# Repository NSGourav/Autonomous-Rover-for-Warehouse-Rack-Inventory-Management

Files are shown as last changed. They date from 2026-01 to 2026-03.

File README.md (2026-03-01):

# Autonomous-Rover-for-Warehouse-Rack-Inventory-Management
INTER IIT TECH MEET 14.0 MP1

## Overview

Designed and built an Autonomous Mobile Robot (AMR) for warehouse inventory management capable of:
- Autonomous navigation inside warehouse aisles
- Vertical scanning of racks up to 1.8 m
- QR-based rack identification
- Real-time inventory data logging
- The system integrates SLAM, ROS2 navigation, differential drive motion, and a belt-driven vertical lift mechanism into a unified workflow.

Official Problem Statement PDF: [Inter IIT Tech Meet 14.0 Problem Statement](https://drive.google.com/file/d/12ET33sytQ0gMRCpAS6UsOaBk7EDwTndu/view?usp=sharing)

## System Architecture

Two-layer architecture:
### Low-Level Control
- Arduino Mega
- DC motor control with encoder feedback
- Stepper motor control for vertical lift
- Emergency stop handling

### High-Level Control
- ROS2 middleware
- slam_toolbox (2D LiDAR SLAM)
- AMCL localization
- Nav2 (path planning + obstacle avoidance)
- OpenCV-based QR detection
- Inventory data logging

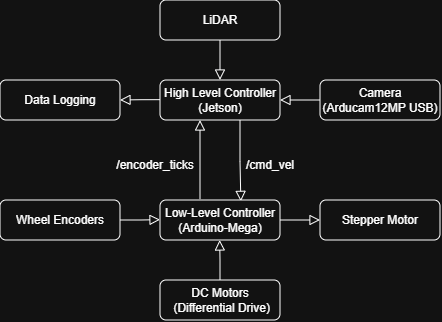
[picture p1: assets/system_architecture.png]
System Architecture


## Launch Files

## Results 
- ±25 cm positioning accuracy over 10 m
- QR detection < 1 second
- 90% QR detection rate
- Control loop at 20 Hz
- ~1 hour runtime (22.2V, 20Ah battery)

🏆 Final Rank: 6th out of 19 IITs

## Demonstration
🎥 Vertical Scanning: [Watch Here](https://drive.google.com/file/d/1KGMI8gQ0bd0-lW-TCqL113q4YaDr5LGW/view?usp=sharing)

🎥 Hardware Demo: [Watch Here](https://drive.google.com/file/d/1Vsa3Wl3Hw1EQ6sBA5-eVvMxNQFey-LZ9/view?usp=sharing)

🛠 CAD Model (Full Assembly): [View on GrabCAD](https://grabcad.com/yourlink)

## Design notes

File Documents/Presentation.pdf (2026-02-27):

# Autonomous Mobile Robot for Warehouse Inventory

## Team ID- 42

## INTER IIT TECH MEET 14.0

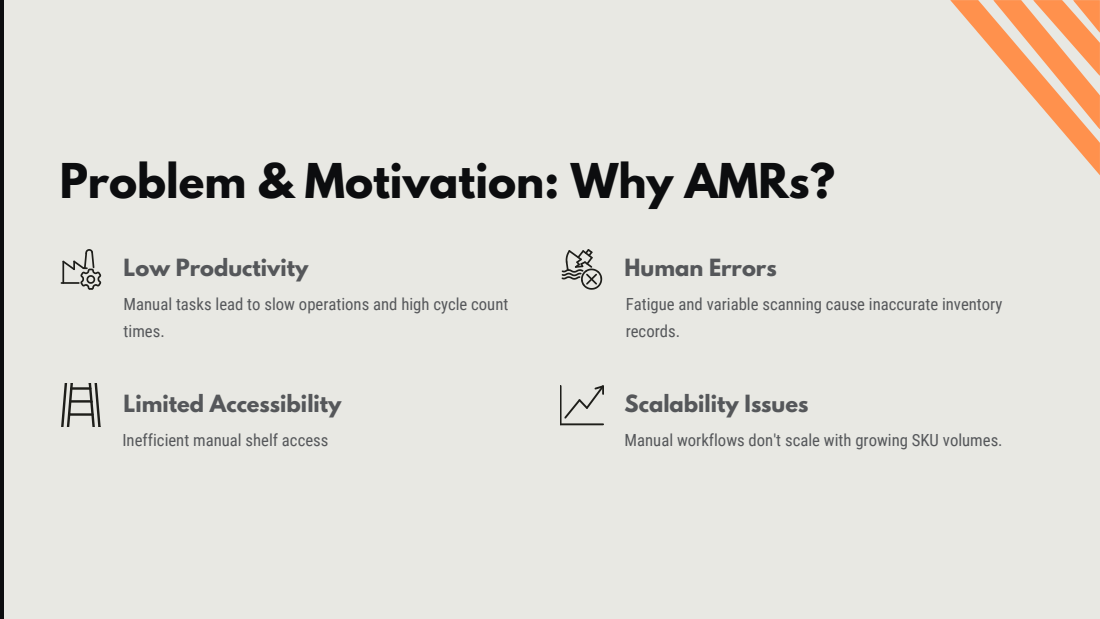
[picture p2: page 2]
Low Productivity; Human Errors; Limited Accessibility; Scalability Issues

Problem & Motivation: Why AMRs?

Manual tasks lead to slow operations and high cycle count
times.

Fatigue and variable scanning cause inaccurate inventory
records.

Inefficient manual shelf access

Manual workflows don't scale with growing SKU volumes.

# Executive Summary: Revolutionizing Inventory

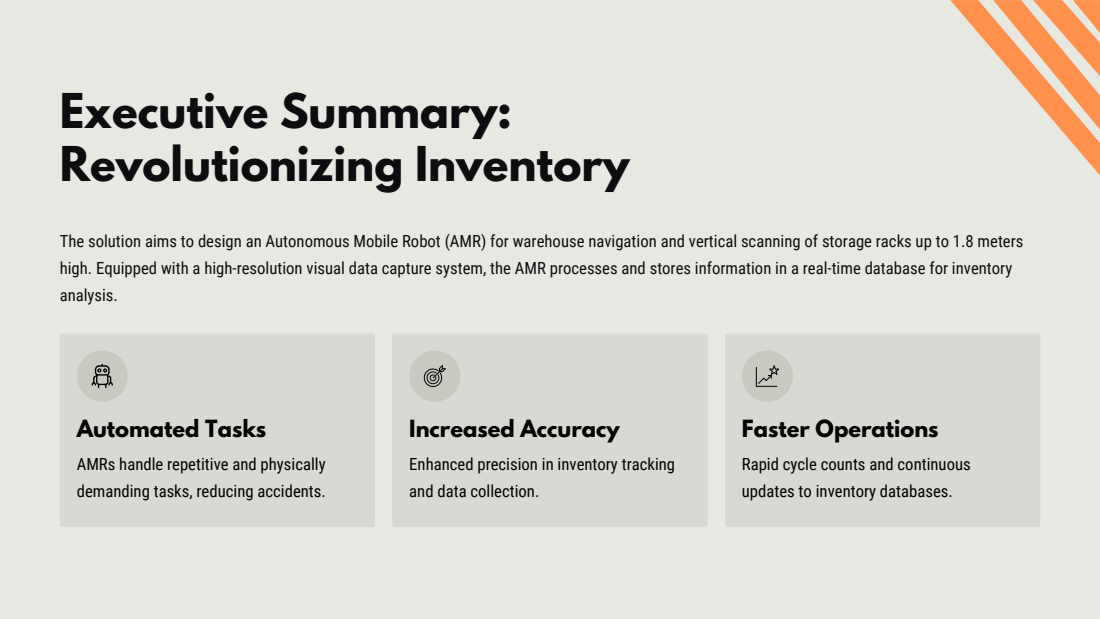
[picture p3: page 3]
Automated Tasks; Increased Accuracy; Faster Operations

The solution aims to design an Autonomous Mobile Robot (AMR) for warehouse navigation and vertical scanning of storage racks up to 1.8 meters
high. Equipped with a high-resolution visual data capture system, the AMR processes and stores information in a real-time database for inventory
analysis.

AMRs handle repetitive and physically
demanding tasks, reducing accidents.

Enhanced precision in inventory tracking
and data collection.

Rapid cycle counts and continuous
updates to inventory databases.

# Solution Approach & Key Metrics

Our AMR integrates SLAM-based navigation, QR scanning, a vertical lift, and data logging. Built with off-the-shelf components, it combines differential drive motion, a camera-based scanning module, and ROS 2 powered algorithms.

## Positioning Accuracy (X-Y)

±25 cm over 10 meters.

## Vertical Lift Accuracy (Z)

Less than 2 cm precision with stepper motor.

## QR Scanning Speed

Less than 1 second per QR code.

## Full Rack Scan

Within 3 minutes, including motion and positioning.

# Control Flow: High & Low Level

## Low-Level Controller (Arduino Mega)

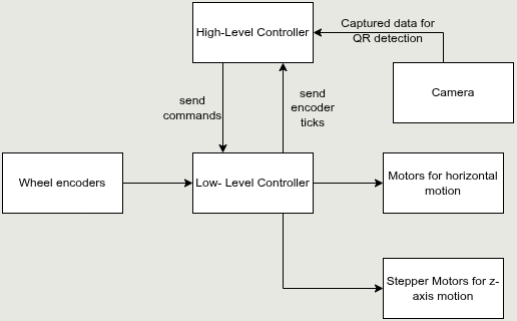
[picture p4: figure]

Provides real-time performance with sufficient GPIO pins and strong interrupt handling. Handles PWM signals and wheel encoder
feedback.

## High-Level Controller

Functions as the computational unit for autonomous navigation, perception, and data processing. Runs ROS 2 middleware for SLAM, localization, and path planning.

The High-Level Controller processes LiDAR data for mapping and visual data for QR code detection, storing information in warehouse servers.

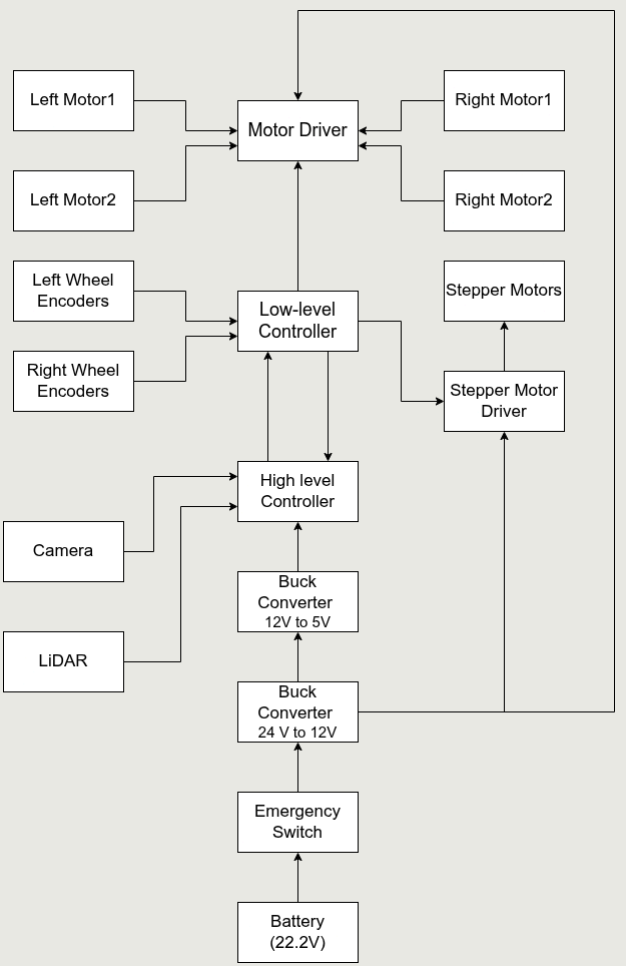
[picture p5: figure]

# Inter-connections between the various components used

# Hardware Design: Motion Systems

## Horizontal Motion: Differential Drive

Four DC motors provide high maneuverability and
precise control. Independent control allows forward/backward movement, turns, and zero-radius pivots for navigating narrow aisles.

## Vertical Motion: Belt-Driven Lift

A 1.5-meter aluminum double-extrusion profile guides a belt-driven linear actuation system. A NEMA stepper motor drives a timing belt, moving a V-slot gantry plate with the camera module.

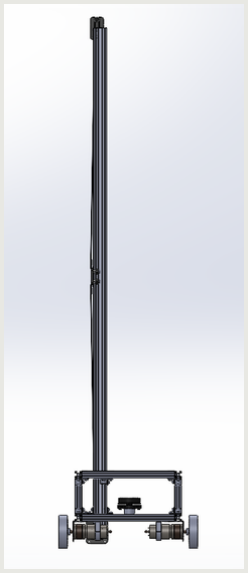
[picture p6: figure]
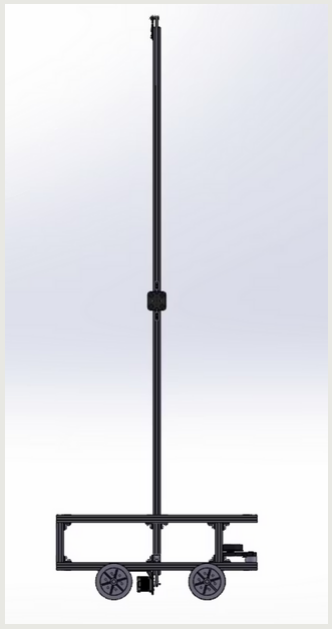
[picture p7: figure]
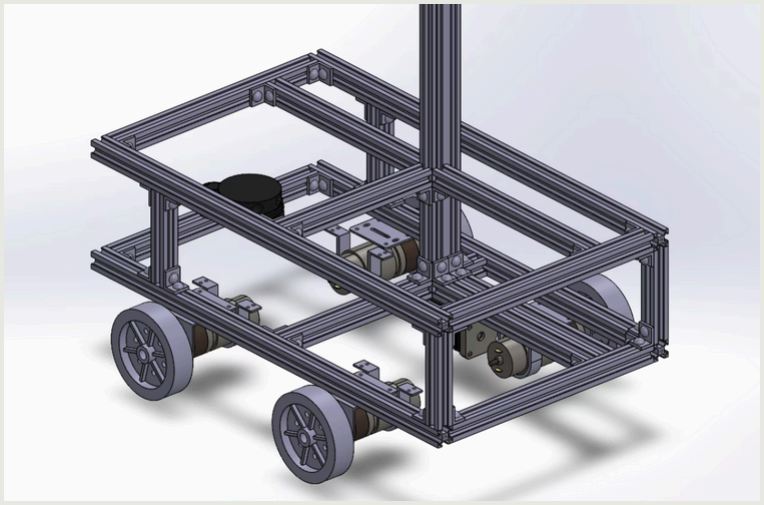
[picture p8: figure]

# Lift Mechanism: A Closer Look

A stepper motor drives a timing pulley connected to a reinforced belt running along the extrusion.
An idler pulley at the top maintains belt tension and eliminates backlash.
The belt is fixed to the V-slot gantry plate, so motor rotation converts directly into vertical motion.
The gantry plate uses four precision rollers to ensure stable, wobble-free travel along the extrusion.
This setup allows the camera module to move smoothly across the full 1.6-meter vertical range for scanning.

# How does it work?

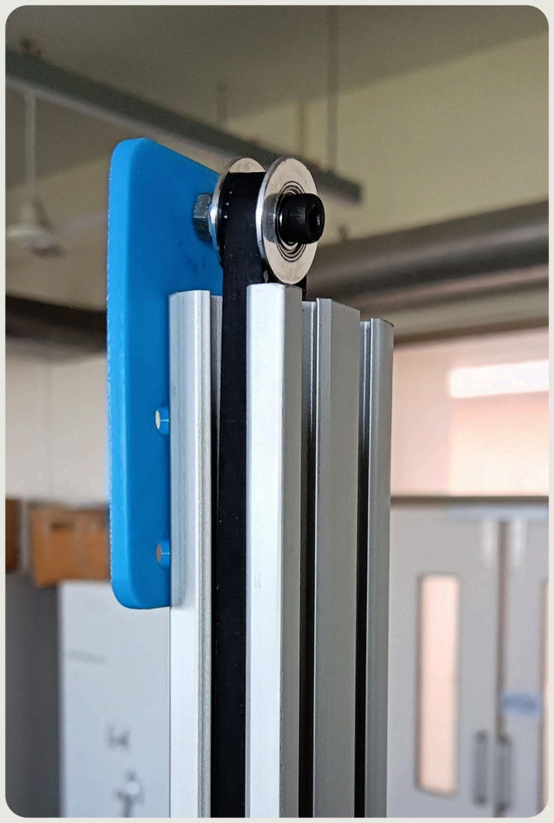
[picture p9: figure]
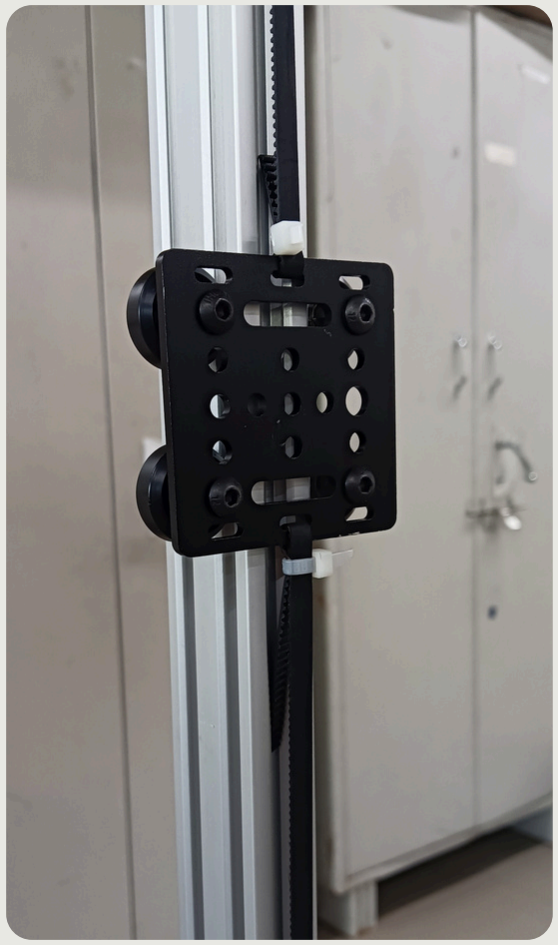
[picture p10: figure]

Pulley & Idler plate | V-slot gantry plate

# Why use belt-driven lift?

Provides high-speed, low-noise, and low-vibration motion suitable for precise camera scanning.
Avoids lead-screw limitations such as screw whip, high friction, reduced speed over long travel, and increased torque demand for tall lifts.
More efficient than telescopic masts, offering continuous, backlash-free motion without complex multi-stage assemblies.
Enables lighter construction, easier maintenance, and better cost-performance for long-range vertical actuation (up to ~1.8 meters).

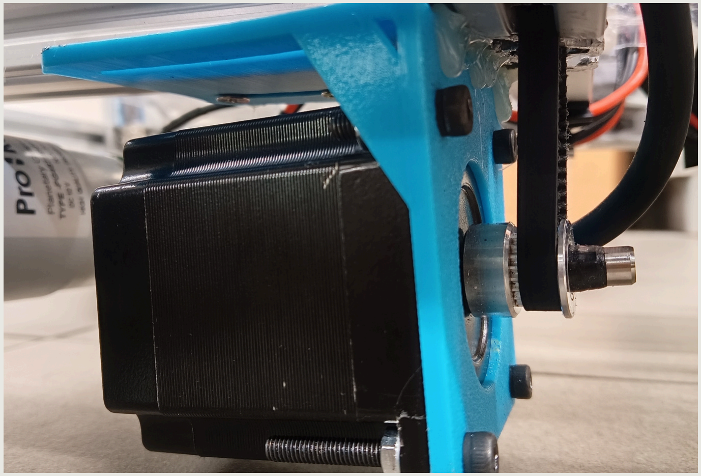
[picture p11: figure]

### Stepper with pulley controlling linear actuation of belt

# Gallery

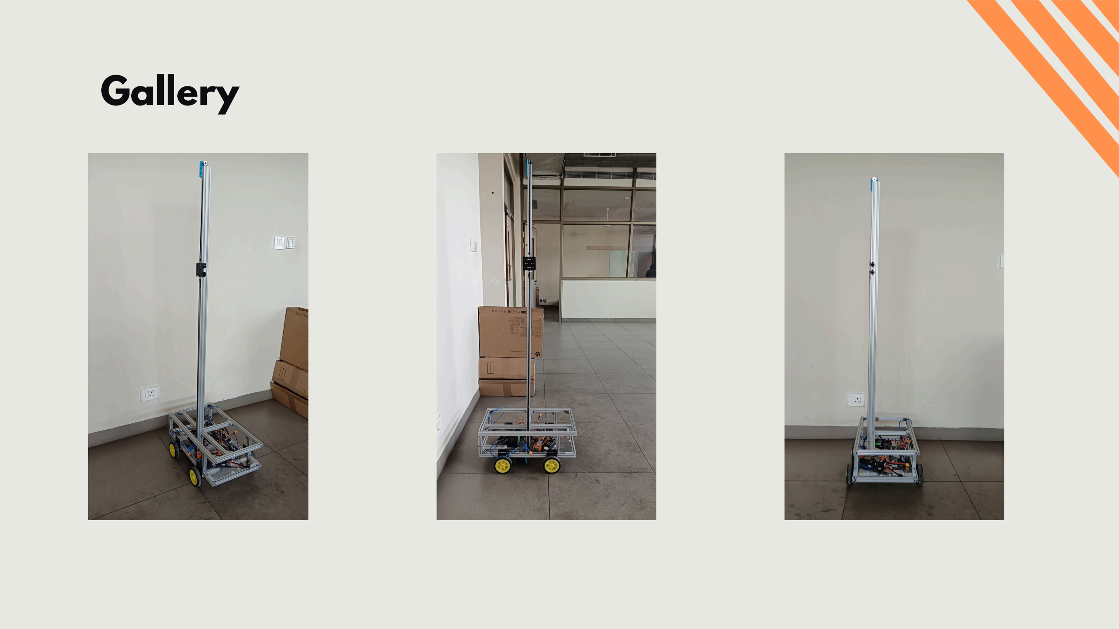
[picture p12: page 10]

# Software Architecture

The AMR's software is built on a modular, ROS 2-based architecture, integrating perception, motion control and navigation. The high level controller handles high-level tasks like localization, path planning etc. while the Arduino Mega manages low-level actuation and sensing.

01

## ROS 2 Operating Framework

Real-time communication, sensor integration, navigation algorithms, and modular scalability.

02

## SLAM & Localization

Uses slam_toolbox for 2D LiDAR-based SLAM, pose-graph optimization, and real-time map correction. AMCL localization for localizing the robot

03

## Navigation Stack (Nav2)

Handles global path planning, local obstacle avoidance, and collision-free trajectory computation.

04

## Vertical Actuation & QR Scanning

Stepper-driven Z-axis lift positions camera at predefined shelf heights. OpenCV + Python script detects and decodes QR codes and stores information locally.

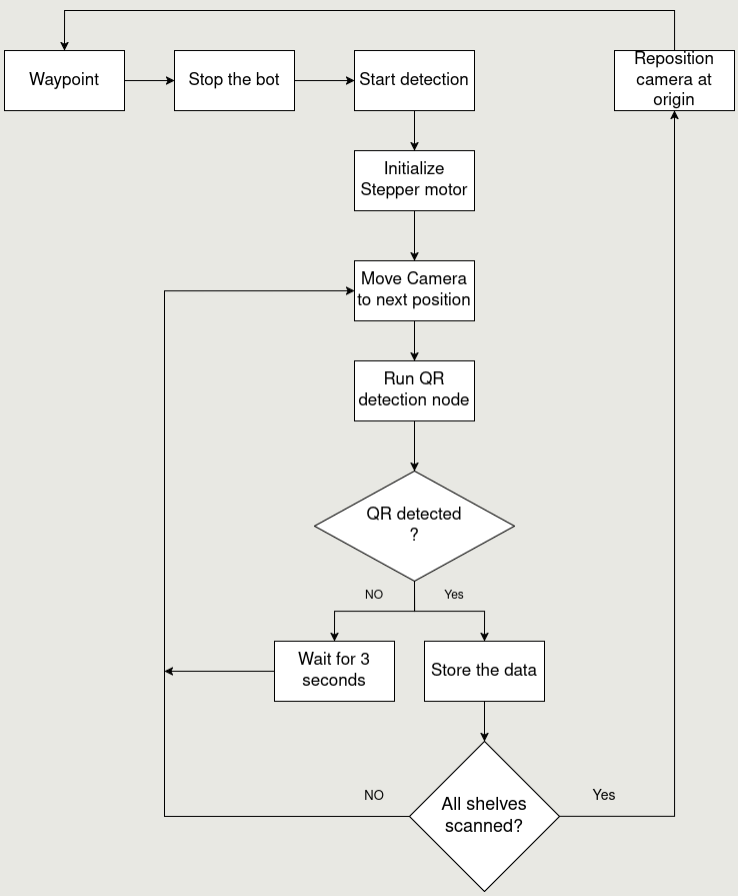
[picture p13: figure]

# QR code scanning and Camera Control mechanism

On reaching the racks, the following processes are being followed for detection of QR codes and acquiring the data stored in them and managing the inventory.

# Testing & Validation

Structured testing in a simulated warehouse environment validated the AMR's performance, reliability, and robustness across various parameters.

1

### Motion & Navigation

Positional accuracy of ±25 cm over 10m traversals. Max speed 0.6 m/s, stopping in 2 seconds.

2

### Vertical Lift System

Less than 2 cm vertical positioning accuracy, 10 mm/s lift speed for quick transitions.

3

### Perception & QR Scanning

QR code detection under 1 second. Full rack scan within 3 minutes.

4

### System Control Stability

Motion control loop operates at 20 Hz for stable autonomous behavior.

5

### Power & Endurance

Up to 1 hour of continuous operation under extreme condition (when using 22.2v ,20Ah battery).

# Future Improvements

Industrial level chasis building.
Recovery Behaviour.
Advanced scanning: dynamic shelf-height detection, adaptive camera, visual SLAM fusion. Implementing Autonomous Docking.

# THANK YOU

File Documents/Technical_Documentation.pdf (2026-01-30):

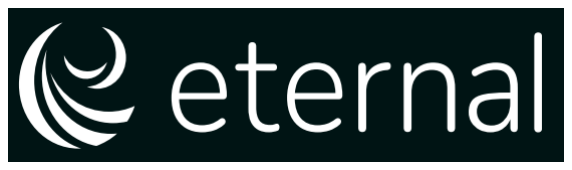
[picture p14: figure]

# Autonomous Rover for Warehouse Rack Inventory Management

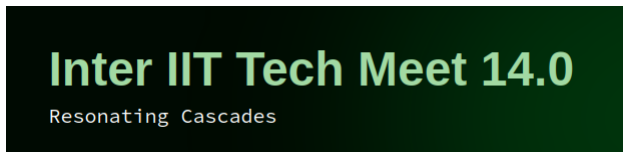
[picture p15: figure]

# End-Term Report

# Team ID: 42

# 6th December 2025

## End-Term Report

Abstract—This report describes the design procedure of an Autonomous Mobile Robot capable of navigating warehouse environments and performing vertical scanning operations on storage racks up to

### 2 meters high.. The AMR is equipped with a high-

resolution visual data capture system that scans the rack contents, processes the information, and stores it in a real-time database for inventory analysis and management. Detailed design concepts, accompanied by CAD files and videos that demonstrate live operation, are included as part of the performance evaluation.

I. EXECUTIVE SUMMARY

Inventory management is a mission-critical task for modern warehouses requiring precise tracking of Stock Keeping Units (SKUs), rapid cycle counts, and continuous updates to inventory databases. Traditionally, this has been done manually, where workers spend a large portion of their time walking long distances, searching for SKUs, climbing racks, and performing repetitive scanning tasks, which leads to fatigue, slow operations, and a high likelihood of human error. This is where Autonomous Mobile Robots (AMRs) greatly improve warehouse inventory management compared to traditional human-based systems by addressing several longstanding operational challenges. AMRs can take over repetitive and physically demanding tasks, reducing workplace accidents and increasing accuracy in less time—more suited to today’s fast paced world of quick orders and deliveries. They provide continuous, reliable, and data-driven inventory tracking that enhances productivity, ensures real-time visibility, and supports faster, error-free order fulfillment.

A. Overview of Solution Approach

Here, we are going to discuss our approach to designing an Autonomous Mobile Robot capable of navigating the warehouse and performing vertical scanning. The robot is built with commercially available off-the-shelf components that can be easily assembled anywhere, making it a suitable choice for this purpose.
The proposed solution integrates SLAM-based autonomous navigation, QR scanning, a vertical lift mechanism, and data logging. The robot uses a modular hardware architecture combining differential drive motion, a camera-based scanning module, and ROS 2 powered perception and planning algorithms.

The core challenge is to develop a vertical scanning mechanism capable of positioning and reading QR codes at pre-defined rack heights across a 2-meter vertical range, while ensuring accurate alignment, stable motion control, and reliable data acquisition.

B. Key Metrics

The performance of the autonomous robotic system has been evaluated and benchmarked across motion, sensing, perception, and operational endurance. The key performance metrics are summarized below:

- Positioning Accuracy (X–Y Axis)
– The robot maintains a positional accuracy of ±25 cm in the X–Y plane over a full traversal length of up to 10 meters.
- Vertical Lift Accuracy (Z Axis)
– The stepper-motor-driven lifting system achieves a precise vertical positioning accuracy of up to 2 cm.
- Z-Axis Lift Speed

– The maximum achievable velocity of the vertical lift stepper motor is 100 mm/s, enabling rapid elevation adjustments for scanning and object interaction.
- Motor Speed and Braking Performance

– The mobile base motors attain a maximum translational speed of 0.6 m/s.
– Motor stopping time from 0.6 m/s to a complete stop: 2 seconds.
- QR Code Scanning Performance

– Vision-based scanning detects and decodes QR markers in less than 1 second.
- Full Rack Scanning Efficiency

– The entire storage rack can be scanned within 2 minutes, including robot motion, positioning, and image acquisition cycles.
- LiDAR Range and Mapping Accuracy
– The LiDAR sensor provides accurate distance measurements up to 1.2 meters.
- System Control Frequency

– The primary motion control loop operates at 20 Hz, ensuring stable feedback for velocity regulation and localization updates in real time.
- Battery Life

– The on-board power system ensures up to 1 hour of continuous operation under typical motion and perception workloads.

II. PROBLEM UNDERSTANDING AND MOTIVATION

A. Productivity

Warehouse staff spend a lot of time walking through the warehouse, searching for SKUs, climbing racks and performing repetitive scanning tasks. This results in low operational throughput and high-cycle count times, especially in case of largescaled facilities.
AMRs can autonomously navigate through the pre-defined layouts of the warehouse, perform routine checks at intervals the operators are free to decide. This would reduce cycle-count times by 3-5 times and significantly improve operations.
B. Susceptibility to Human Errors

Manual scanning introduces inconsistencies due to operator fatigue, variable scanning angles, and improper documentation. This leads to inaccurate inventory records, misaligned stock levels, and higher chances of order fulfillment errors.
With controlled motion, fixed scanning geometry, and computer vision algorithms, AMRs ensure consistent barcode/QR readability and eliminate variability caused by human operators.
C. Limited Accessibility to Vertical Storage

Racks extending up to 2 meters require operators to climb ladders or use lifting equipment for scanning. This increases inspection time and introduces ergonomic and safety risks—particularly in narrow warehouse aisles.
The AMR integrates a vertical lift mechanism that moves the camera from bottom to top automatically. This ensures safe, fast, and complete scanning of all shelf levels without requiring human intervention.
D. Scalability

As SKU volume grows, manual inventory workflows do not scale well. Long traversal paths and repetitive scanning behaviors drastically increase workload and reduce operational agility, especially during peak seasons.
AMRs scale effortlessly—we would just need to deploy more robots or increase the scanning frequency. Their autonomous operation allows covering large areas efficiently and consistently. Robots can also operate continuously with predictable behavior and accuracy, enabling 24/7 inventory monitoring with minimal downtime.
E. Need for Data-Driven, High-Resolution Inventory Records

Modern supply chains rely heavily on fast, accurate, and data-rich inventory snapshots. Manual scanning rarely provides high-resolution images or structured digital logs, limiting traceability.
AMRs capture high-resolution shelf images, QR/Barcode metadata, and timestamped logs in a structured digital format suitable for analytics and automated reconciliation.
F. Alignment with Industry 4.0 and Smart Warehousing

Adopting AMR-based scanning aligns with Industry 4.0 goals—smart warehousing, data-driven analytics, and integration of cyber-physical systems. The shift from manual audits to automated continuous scanning significantly enhances operational visibility and scalability.
AMRs serve as cyber-physical systems that integrate mobility, perception, and real-time data communication—laying the foundation for smart warehousing, predictive analytics, and full automation.
G. Performance Objectives

Through the design and construction of a functional AMR suitable for Warehouse management system, we would like to achieve the following added improvements over the presently used solutions:

- Demonstrate a scalable warehouse automation solution
- Reduce manual efforts by more than 80%.
- Improve safety while scanning vertical heights.
- Achieve better accuracy with data logging and inventory management.
- Provide Real-Time Inventory Visibility
- Showcase Integration with Existing Warehouse Systems
- Optimize costs and durability.
- Prepare a safe, collision avoidant system for humans and robots to work together.

III. SYSTEM ARCHITECTURE

A. Power and Motor Control

The drive motors are powered directly from the robot’s primary battery system, chosen to match the current and voltage requirements of the motor drivers. High-current motor driver modules interface between the motors and the embedded control electronics. Each motor driver provides:

- Direction control
- PWM-based speed control
- Overcurrent prevention
- Heat-sinks for thermal protection

This ensures reliable motor performance even during extended operation in 0°C–40°C warehouse conditions.

B. Control Flow Architecture

The robot uses a two-tier control system to balance high-level intelligence and processing power with low-level real-time responsiveness for achieving maximum output in minimum time.

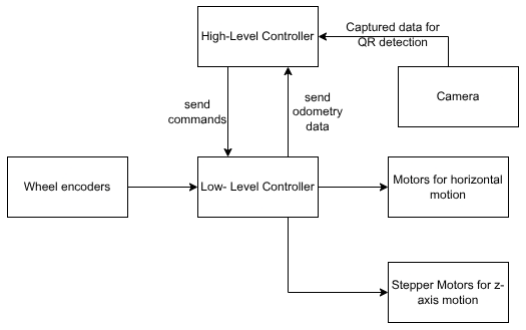
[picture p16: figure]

Fig. 1: 2-level Controller

1) Low-Level Controller: The Arduino Mega 2560 Rev3 board has been used as the onboard controller because it provides an excellent real-time performance with sufficient GPIO pins, multiple hardware serial ports, strong interrupt handling capabilities, seamless compatibility with motor drivers. It is used for:
- Receiving high-level commands from the high level controller Jetson Nano through UAR-T/I2C/serial
- Generating PWM signals for motor drivers
- Executing differential-drive kinematics in real time
- Handling wheel encoder feedback
- Ensuring immediate response for braking or velocity correction

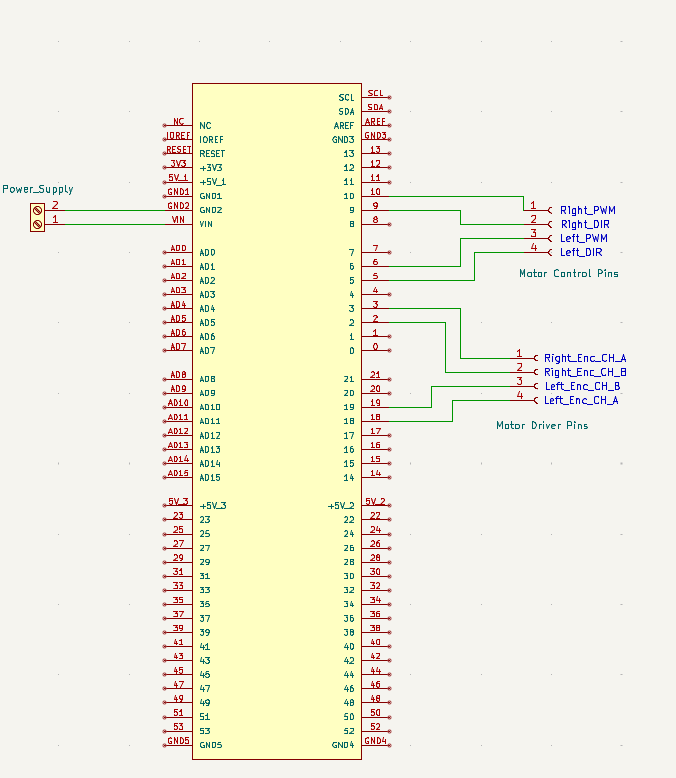
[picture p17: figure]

Fig. 2: Schematics

2) High-Level Controller: The NVIDIA Jetson Nano functions as the high-level computational unit responsible for autonomous navigation, perception, data processing, and system coordination. It runs the full ROS 2 middleware, acting as the central node that integrates the robot’s sensing, decision-making, and communication subsystems. It handles the following critical tasks:
- ROS2 based Autonomous Navigation The Nano runs ROS 2 nodes for:
– SLAM (Simultaneous Localization and Mapping) Using LiDAR data to construct and update a real-time 2D map of the warehouse. – Localization Tracking the robot’s position on the generated map.
– Path Planning and Path Following Generating obstacle-free trajectories and converting them into high-level movement commands. – The LiDAR is directly connected to the Jetson Nano via USB or serial, and its data is processed through ROS 2 packages such as slam-toolbox, nav2, or equivalent.

Algorithm 1 SLAM Algorithm for Autonomous Mobile Robot (AMR)
1: Initialization:
2: Initialize robot pose estimate xˆ0
3: Initialize map representation M0 (empty or prior map)
4: Initialize motion model and sensor model parameters
5: Set time step t = 0

6:
7: while robot is operational do
8: | t ← t + 1
9: | Input:
10: | Receive control commands ut (odometry,
| wheel encoders)
11: | Receive sensor measurements zt (LiDAR)

12:
13: | Map Update:
14: | Add new landmarks or update existing ones
| in Mt
15: | Update occupancy grid / feature map using
| zt and xˆt

16:
17: | Output: Updated pose estimate xˆt and map
| Mt
18: end while
- Sensor Fusion and Perception The Nano is
| connected to LiDAR for scanning the environ-
| ment for running Simultaneous Localization
| and Mapping (SLAM) algorithms and generat-
| ing point clouds. The visual data captured in
| the camera is also processed by the Nano for
| QR code detection and data retrieval. The data
| obtained is stored in the Warehouse servers.
- Server Communication and Monitoring The
| Jetson Nano maintains wireless connectivity
| with warehouse infrastructure to:
| – Upload camera scans
| – Stream robot status
| – Send mapping/navigation logs
| – Fetch mission instructions or scheduled
| scanning tasks
| This allows real-time synchronization between
| the robot and the warehouse management
| system (WMS).
| IV. HARDWARE DESIGN

The hardware is built with commercially available off-the-shelf components. The vertical lifting subsystem is designed to enable precise, stable, and repeatable elevation of the camera module for high-rack inventory scanning within warehouse environments.

A. Horizontal motion

The horizontal motion of the AMR is achieved by a differential drive mechanism, designed for high maneuverability, robustness, and precise motion control within warehouse environments.
1) Differential Drive Configuration: The platform utilizes four DC motors, arranged with two motors on each side to maximize traction, payload capacity, and stability during operation. They are controlled by commands from the onboard Microcontroller. Independent control of left and right motor groups allows the robot to: Move forward/backward by driving both sides in the same direction, perform turns by differential wheel speeds, execute zero-radius (pivot) turns by driving the sides in opposite directions. This configuration enables smooth navigation through narrow warehouse aisles, tight corners, and dynamic environments with obstacles and human movement.
B. Vertical Motion and Lift Mechanism

The robot utilizes a 2-meter aluminum doubleextrusion profile as the primary structural guide, offering high rigidity, low weight, and excellent resistance to flexing under vertical loads.
A belt-driven linear actuation system is implemented to provide smooth and controlled vertical motion. At the base of the extrusion, a NEMAseries stepper motor is mounted securely using a motor-mounting plate. The motor shaft drives a timing pulley, which engages with a reinforced GT2/HTD timing belt running along the length of the extrusion.
At the upper end of the extrusion profile, an idler pulley assembly is positioned using an idler plate. The belt passes over this idler pulley, allowing for proper tensioning and minimizing backlash. The belt loop is routed such that one segment is fixed to a V-slot gantry plate equipped with precision rollers. As the stepper motor rotates, the belt’s motion directly translates into linear displacement of the gantry plate along the extrusion.
The V-slot gantry plate provides stable 4- or 6-wheel contact with the extrusion profile to ensure smooth, low-friction vertical motion while maintaining alignment under lateral forces. The camera module is rigidly mounted to this gantry plate, enabling it to traverse 1.60-meter height for rack scanning operations.

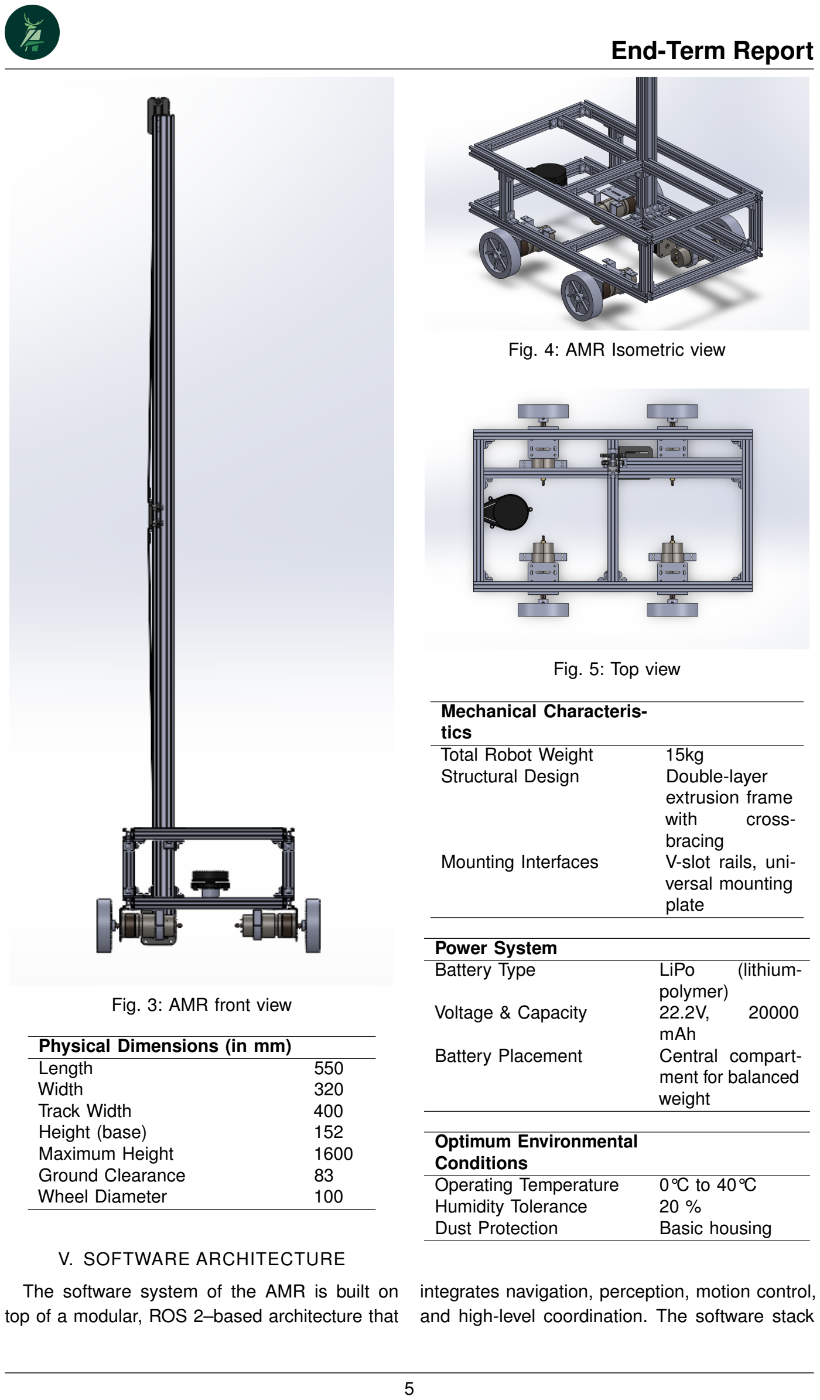
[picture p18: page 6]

Fig. 3: AMR front view

Physical Dimensions (in mm)
Length | 550
Width | 320
Track Width | 400
Height (base) | 152
Maximum Height | 1600
Ground Clearance | 83
Wheel Diameter | 100
V. SOFTWARE ARCHITECTURE

The software system of the AMR is built on top of a modular, ROS 2–based architecture that

Fig. 4: AMR Isometric view

Fig. 5: Top view

Mechanical Characteristics
Total Robot Weight | 15kg
Structural Design | Double-layer
extrusion frame
| with | cross-
| bracing
Mounting Interfaces | V-slot rails, uni-
versal mounting
| plate

Power System
Battery Type | LiPo | (lithium-
| polymer)
Voltage & Capacity | 22.2V, | 20000
| mAh
Battery Placement | Central compart-
ment for balanced
| weight

Optimum Environmental
Conditions
Operating Temperature | 0°C to 40°C
Humidity Tolerance | 20 %
Dust Protection | Basic housing

integrates navigation, perception, motion control, and high-level coordination. The software stack

Current Analysis | Value
Jetson Power Draw | 2A
Arduino Mega (each) | 0.5A
DC Motor Power (ideal) | 2A × 4 = 8A
DC Motor Power (maximum)

4A × 4 = 16A

Stepper Motor (each) | 2.8A
Camera & LiDAR | Powered by Jet-
| son
Motor Driver Rating | 10A | (normal),
30A (peak)
Stepper Motor Driver Rat- ing | 4A

runs primarily on the NVIDIA Jetson Nano, while low-level actuation is handled by the Arduino Mega. The system supports autonomous warehouse navigation, LiDAR-based mapping, Z-axis scanning, QR-code detection, and structured inventory data storage.

A. Operating Framework: ROS 2

The robot uses ROS 2 as its core middleware. ROS 2 provides:Real-time communication between software nodes, Sensor integration, Navigation algorithms, Visualization tools, Modular software scalability
ROS 2 nodes running on the Jetson Nano interact with the LiDAR, Z-axis lift systems, camera, and the Arduino Mega.
B. SLAM and Localization

For mapping and continuous localization, the system uses slam toolbox, a ROS 2 package optimized for real-time warehouse-scale SLAM.

- 2D LiDAR-based SLAM
- Pose-graph optimization
- Loop closure
- Real-time map correction
- Persistent map saving
C. Odometry

Odometry is obtained by fusing multiple sensor sources:

- Wheel Encoders measure how much the wheels have rotated, allowing the robot to estimate how much it has moved. When we combine these measures for left and right wheels, we can get the position and orientation.
D. Navigation Stack

The autonomous navigation layer is built using Nav2, the standard ROS 2 navigation framework. Nav2 handles:

- Global path planning
- Local obstacle avoidance
- Costmap generation
- Path smoothening
- Behavior trees for mission execution

Using LiDAR data and the SLAM-generated map, Nav2 computes collision-free trajectories between rack aisles and scanning locations.

E. High-Level Command Execution

The Jetson Nano acts as the decision-making brain. All path planning, SLAM, and perception algorithms run on the Nano. Once the desired linear and angular velocities are computed, they are transmitted to the Arduino Mega using a serial protocol.
Jetson to Arduino Communication:
- Jetson Nano publishes /cmd vel velocity commands
- A bridge script converts ROS 2 velocity messages into serial commands
- Arduino Mega receives:
- Target linear velocity
- Target angular velocity
- Motion mode (forward, rotate, stop)
- Arduino handles real-time PWM generation for all four motors

This ensures smooth, deterministic execution of motion commands without OS-induced delays on the Jetson.

F. Imaging & QR Code Scanning Pipeline

The AMR performs vertical rack scanning using a stepper-driven Z-axis lift equipped with a camera. The scanning pipeline operates in discrete height levels that match warehouse shelf elevations.
1) Controlled Z-Axis Positioning: During a scan:
- Nav2 positions the robot in front of the rack.
- Motion is halted to eliminate vibrations.
- The Z-axis controller raises/lowers the camera to predefined shelf heights.
- Stabilization delay ensures sharp images.

Algorithm 2 Camera Position Control using Stepper Motors
1: Input: Target rack heights H = {45, 87, 130} cm
2: Constants:
3: | Srev = 200 steps per revolution
4: | Drev = 5.027 cm belt travel per revolution
5: | Scm = Srev/Drev steps per cm

6:
7: ROS2 Node (Publisher):
8: Initialize prev height = 0
9: for each h in H do
10: Compute incremental distance:

d = h − prev height

11: Compute required steps:

steps = d × Scm

12: | Publish | steps | on | topic
/camera_lift/steps
13: Update previous height:

prev height = h

14: end for
15: Arduino Node (Subscriber):
16: while | message | received | from | topic
/camera_lift/steps do
17: | Read incoming step command steps
18: | Drive the stepper motor for steps steps
19: | Stop motor movement
20: | Wait for 5 seconds to capture QR
21: end while

22:
23: Camera Operation:
24: for each halt position do
25: | Run detection script
26: | Extract QR data and append to JSON file
27: end for
28: End Algorithm
2) QR Code Detection (OpenCV + Python): A Python script running on the Jetson Nano uses OpenCV QR detection to process each captured image:
- Detects and decodes QR codes
- Extracted | data | is | of | the | form
RACKID_SHELFID_ITEMCODE | which | is
parsed and stored in a CSV file
- Validates code integrity
- Handles low-contrast cases with preprocessing (thresholding, sharpening, etc.)

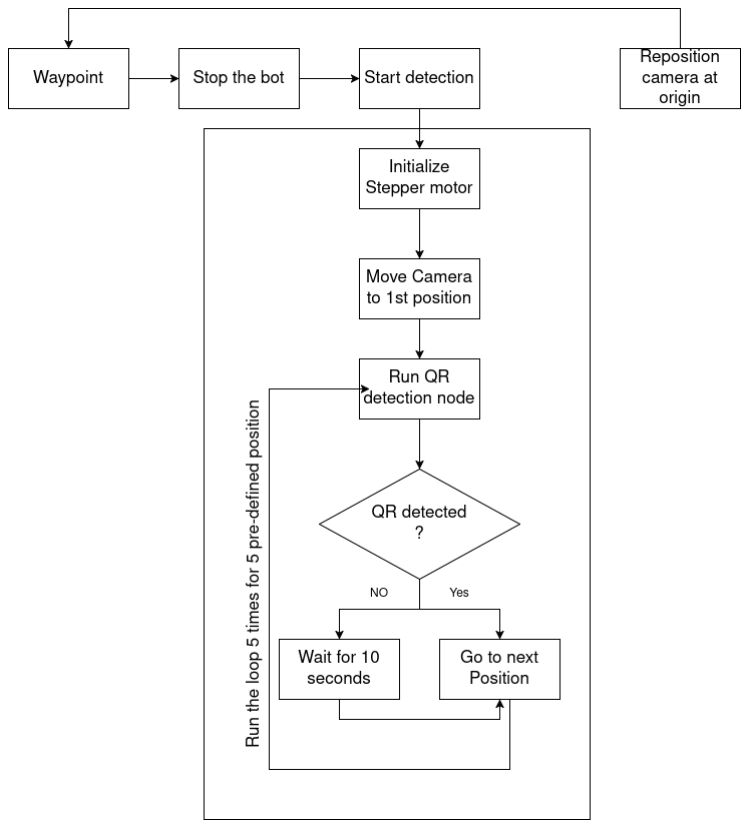
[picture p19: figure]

Fig. 6: QR detection mechanism

VI. INTEGRATION AND CONTROL

The autonomous mobile robot (AMR) integrates hardware and software components to achieve precise navigation and task execution within warehouse environments. Control and motion execution are handled using the ROS2 framework, which provides modular and real-time communication between nodes.

A. Motion Control
- The AMR uses ROS2 Control to interface with motor drivers and sensors, providing a hardware-agnostic control layer. Wheel velocities and actuator commands are sent via ROS2 controllers, allowing seamless integration with higher-level planning.
- Sensor feedback, including wheel encoders
- A PID controller processes velocity errors and generates motor commands, ensuring accurate tracking of the desired trajectory.
B. Navigation
- The AMR employs Nav2 stack for autonomous navigation. It performs mapping, localization, path planning, and obstacle avoidance within the warehouse.
- Real-time sensor data is fused to create an up-to-date occupancy grid, which is used by the planner to compute collision-free paths.

- Motion commands from the planner are translated into wheel velocity setpoints, which are tracked by the PID controller via ROS2 Control.
C. Integration Workflow
- High-level navigation goals are sent to the Nav2 stack, which computes safe paths for the robot to follow.
- ROS2 topics and services handle communication between the navigation stack, perception nodes, and low-level control nodes.
- Safety mechanisms, including emergency stops and collision detection, are integrated to override commands if required, ensuring reliable and safe operation.

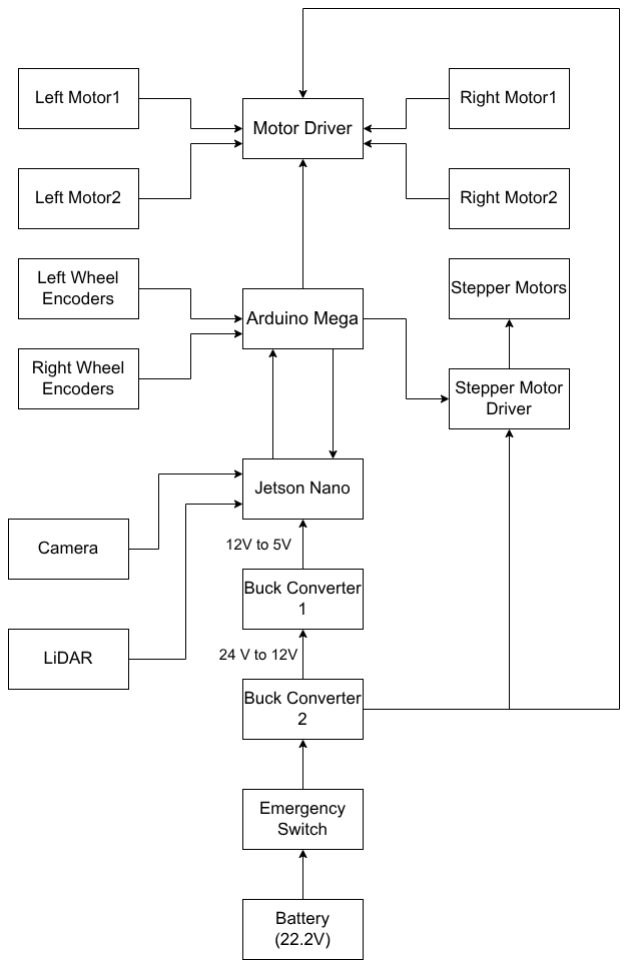
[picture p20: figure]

Fig. 7: Circuit Connection Flow

Algorithm 3 Updating positions from Wheel Encoder
1: Initialization:
2: Set PID gains: Kp, Ki
, Kd
3: Initialize error, integral, and derivative terms to zero
4: Initialize robot pose variables (x, y, θ)

5:
6: Loop executed every fixed time interval: 7: Read the current encoder tick counts for the left and right wheels.
8: Compute tick difference:
9: ∆ticks = tickscurrent − ticksprevious
10: Calculate RPM from wheel encoder data:
11: ω =

∆ticks
Nrev

·

60
∆t

, where Nrev = ticks per revolution
12: Convert wheel speeds into linear velocities for each wheel:

13: vmeasured = ω · R ·

2π
60
14: Compute measured body velocities:

15: ωbody =

vright−vleft
W
16: vbody =

vleft+vright
2
17: Update robot pose (x, y, θ): 18: x ← x + vbody cos(θ) ∆t 19: y ← y + vbody sin(θ) ∆t

Algorithm 4 PID Error and Target RPM Calculation

1: Compute target wheel RPM from commanded velocity:

2: ωtarget =

vtarget·60
2πR
3: Calculate wheel velocity error:

4: ωerror = ωtarget − ωmeasured
5: Update integral term:
6: I ← I + ωerror · ∆t
7: Compute derivative term:

8: D =

ωerror−ω

prev
error
∆t
9: Store current error for next iteration:
10: ω

prev
error ← ωerror
11: Compute PID output as: u = Kp · ωerror + Ki

·
I + Kd · D

12:

VII. TESTING AND VALIDATION

To evaluate the performance, reliability, and operational robustness of the autonomous warehouseinspection robot, a structured testing and validation procedure was conducted. All experiments were performed inside a controlled arena designed to resemble a real warehouse layout. The arena consisted of consecutive racks arranged in parallel aisles, allowing the robot to navigate, scan, and record data from each rack in a manner consistent with industrial storage environments. Each rack contained multiple QR-coded markers, and the robot was tasked with scanning them sequentially using its onboard perception and vertical lift system.

A. Motion and Navigation Validation

The robot’s movement through the warehouse aisles was assessed by measuring its X–Y planar positioning accuracy over repeated traversals of up to 10 meters. The system consistently maintained a positional deviation of ±25 cm, confirming that the fusion of wheel odometry and LiDAR-based sensing provided stable, repeatable navigation in cluttered indoor spaces.
The motor speed and braking performance were also evaluated. The mobile base achieved a peak translational velocity of 0.6 m/s, and braking tests showed that the robot could decelerate from maximum speed to a complete stop within 2 seconds. These tests validated that the motion controllers ensured both responsiveness and safety when operating around racks and confined spaces.
B. Vertical Lift System Testing

The vertical scanning mechanism, powered by a stepper motor, was tested across multiple rack levels to verify precision and repeatability. The lift system demonstrated a vertical positioning accuracy of 2 cm, allowing the camera to align correctly with QR codes placed at different heights. The lift could reach its maximum speed of 100 mm/s, enabling quick transitions between rack levels without compromising stability.

C. Perception and QR Scanning Validation

The vision pipeline was evaluated using QR markers affixed on every rack surface. Testing showed that the system could detect and decode each QR code in under 1 second, even under minor lighting variations. For full-rack testing, the robot completed the entire scanning sequence—including navigation, lift adjustments, and image acquisition—within 2 minutes per rack, demonstrating high operational efficiency.

D. LiDAR-Based Mapping and Sensing

To validate environmental awareness, the onboard LiDAR was tested for range and measurement consistency. The sensor reliably measured distances up to 6 meters with high accuracy, which was crucial for real-time obstacle detection and localization during aisle traversal.

E. System Control Stability

The robot’s real-time performance was further validated through monitoring of the control loops. The primary motion control system operated at 20 Hz, ensuring that velocity control, pose estimation, and feedback corrections occurred with sufficient frequency for stable autonomous behavior in dynamic warehouse environments.

F. Power and Endurance Testing

Finally, battery endurance tests were conducted under typical navigation and perception workloads. The system sustained up to 1 hour of continuous operation, confirming that the onboard power distribution and consumption were optimized for warehouse-scale inspection tasks.

VIII. LIMITATIONS AND FUTURE SCOPE

A. Current Limitations
1) Linear Z-Axis Lift Mechanism (Fixed 2m Rod): The current vertical scanning mechanism uses a rigid 2m linear rod with a sliding camera mount. While functional, this approach poses several limitations:
- High Structural Load: The long, fully exposed rod introduces bending stress and requires additional stabilizers to prevent oscillation.
- Poor Deployability: The mechanism remains continuously extended, increasing the center of mass and limiting movement under lowclearance obstacles.
- Vibration Sensitivity: The long unsupported length amplifies micro-vibrations, causing motion blur and inconsistent QR detection.
- Energy Inefficiency: The lift motor must continuously counteract the entire mass of the rod, reducing system efficiency.
- Mechanical Wear: Sliding bearings and rails experience increased friction due to longstroke operation.
2) Wiring, Cable Routing, and Connector Reliability: The current wiring approach limits long-term durability and robustness:
- External wiring along the lift increases the likelihood of cable fatigue and entanglement.
- Lack of strain-relief and proper flex channels leads to connector stress and electrical noise.
- Exposed signal and power lines are vulnerable to dust, collisions, and motion-induced degradation.

3) Structural and System-Level Design Constraints:
- Limited spatial optimization results in tightly packed components that reduce maintainability.
- Sensor mounts rely on basic brackets, limiting calibration accuracy and requiring frequent manual adjustments.
- The non-collapsible mast contributes to suboptimal weight distribution and reduced navigation stability.
4) Partial Automation in Scanning Workflow:
- The scanning process requires predefined height inputs rather than adaptive shelf-height detection.
- Limited scan-field optimization may cause redundant captures or incomplete coverage.
B. Future Scope and Improvements
1) Telescopic Mast-Based Z-Axis Mechanism: Replacing the current rod with a multi-stage telescopic mast can significantly improve performance:
- Compactness: Collapses into a low profile during navigation, improving safety and maneuverability.
- Higher Stability: Multi-stage structures offer improved rigidity and reduced vibration.
- Energy Efficiency: Less mass is lifted per stage, reducing motor load.
- Mechanical Protection: Enclosed mast housing protects the camera and cables when retracted.
2) Improved Cable Management Using Drag Chains:
- Integration of cable drag chains ensures stress-free motion along the Z-axis.
- Industrial-grade connectors (M8/M12) improve vibration resistance.
- Shielded cables and ferrite cores can reduce electromagnetic interference.
3) Modular and Service-Friendly Mechanical Architecture:
- Modular sensor mounts enable fast replacement and easy recalibration.
- Optimized chassis design using lightweight profile extrusions enhances internal routing.
- Repositioned battery and electronics improve center-of-gravity and stability.
4) Advanced Scanning Intelligence:
- Dynamic shelf-height detection using depth cameras or ultrasonic sensors.
- Adaptive camera exposure and focus for varying warehouse lighting.
- Real-time completeness validation to ensure no gaps in scanning.
- Fusion of visual SLAM with scan data for improved localization accuracy.
5) Enhanced Autonomy and Navigation:
- Multi-floor map support and coordinated multirobot navigation.
- Integration with warehouse management systems (WMS) for automated task scheduling.
- Dead-reckoning correction via sensor fusion (encoder + LiDAR).
6) Industrial-Grade Shock Isolation:
- Use of isolation mounts or passive dampers for improved scan stability.
- Future integration of active stabilization for high-precision camera imaging.

IX. USER MANUAL

While the robot is capable of autonomous navigation , basic operational safety standards and practices must be practiced while using it on a day-to-day basis.

A. Safety Guidelines
1) General:
- Do not operate the AMR in areas with unauthorized personnel.
- Keep hands, clothing, and loose items away from wheels, lift mechanisms, and moving parts.
- Ensure the robot operates only on clean, flat surfaces free of debris.
- Do not attach external equipment without approval.
2) Electrical:
- Only trained personnel should handle the battery connection or charger.
- Avoid exposing the robot to liquids, extreme heat, or corrosive environments.
- Disconnect power before performing any repairs or modifications.
3) Mechanical:
- Keep hands away from the vertical lift assembly during operation.
- Do not force or manually pull the lift—this could damage motors or gears.

4) Operational Safety:
- Maintain at least 1 meter of clearance around the robot during operation.
- Ensure emergency stop (E-Stop) buttons are functional before every run.
- Do not obstruct or block the LiDAR, camera, or ultrasonic sensors.
- If the AMR behaves unpredictably, press the E-Stop immediately.
B. Operation Guide
1) Pre-Operation Checklist: Before powering the AMR:
- Verify battery level is above 30
- Inspect wheels and lift for debris or obstructions.
- Ensure LiDAR and camera lenses are clean.
- Confirm Wi-Fi or wired communication links are active (if applicable).
- Test the E-Stop.
2) Powering ON:
- Turn ON the main power switch.
- Wait for onboard computer to boot (10–20s).
- Check LED indicators for system health: Green: ready
Yellow: warnings (e.g., low battery)
Red: fault detected
3) Navigation & Scanning Operation:
- Select the scan route from the control interface.
- Robot begins navigation and raises the camera to assigned rack heights.
- QR/Barcode data is captured and logged.
- When the scan run completes:
- Robot returns to the starting point or docking station.
- Data is uploaded to the inventory system.
4) Powering OFF:
- Park the robot in its safe zone/dock.
- Turn OFF the main power switch.
C. Emergency Guidelines
- Press the red Emergency Stop (E-Stop) button to immediately cut power to motors.
- To resume: twist and release the E-Stop, then restart the robot.
- Battery Emergency:
– If battery overheats or swells:
– Power off immediately
– Move robot away from personnel – Contact maintenance team
D. Storage Guidelines
- Store the AMR in a cool, dry, dust-free environment.
- Avoid exposure to direct sunlight, moisture, or extreme temperatures.
- Maintain the battery between 40–60% charge for long-term storage.
- Cover LiDAR, camera, and lift mechanism with protective dust caps if unused for more than 7 days.
- Power off the robot completely before storage.
E. Transportation Guidelines
- Use the provided transport locks to secure the lift mechanism during movement.
- Turn off the main power switch before transportation.
- Ensure the robot is positioned upright; avoid tilting or flipping.
- Use a padded crate or trolley for long-distance transport to avoid vibration damage.
- Avoid stacking heavy objects on the robot.
- If transporting by vehicle, secure the robot with straps to prevent shifting.
X. MAINTENANCE

Proper maintenance ensures reliable operation, longer component lifespan, and consistent scanning accuracy. This section outlines preventive maintenance intervals, replacement parts, and guidelines for safe storage and transportation of the AMR.

A. Daily Maintenance
- Clean camera and LiDAR lenses with microfibre cloth.
- Inspect wheels and castor rollers for dust and dirt.
- Ensure the battery level is sufficient and check for abnormal heating.
- Check vertical lift rails for smooth travel and look for obstructions.
B. Weekly Maintenance
- Validate Encoder readings for detecting drift or slippage in wheels
- Examine the lift mechanism, checking belt tension and alignment.
- Inspect all wires for connections and proper insulation.
- Clean air vents, cooling fans, and onboard computer housing.

C. Monthly Maintenance
- Lubricate lift rails, lead screws, or belts (if applicable) using manufacturer-recommended lubricants.
- Inspect motor mounts, gearboxes, and chassis frame for cracks or deformation.
- Test wheel alignment and adjust caster orientation if drift is observed.
- Perform a full software/firmware update, including ROS packages and navigation maps.
- Conduct a complete functional audit: navigation, scanning, lift actuation, and battery performance.
D. Replacement of Parts

Only authorized replacement components should be used to ensure safety and compatibility.
- Wheel assembly: wheel, encoder, motor shaft coupling
- Battery pack: Li-ion or LiFePO4 module
- Lift system components: belts, lead screws, pulleys, bearings
- LiDAR lens cover (if scratched or cracked)
- Camera module: lens, mount, or protective casing
- Fuses, wiring harnesses, connectors
- Cooling fans and filters
E. Replacement Guidelines
- Always power off the AMR before replacing any part.
- Use only manufacturer-recommended components to avoid calibration issues.
- After replacing lift or drive components, perform a calibration check.
- Keep a log of all part replacements for maintenance records.

XI.

REFERENCES

[1] ROS 2 Humble Documentation, Open Robotics, 2020. Available online: https://docs.ros.org/en/humble/index.html (accessed: 2025).
[2] G. | Bradski, | “The | OpenCV | Library,” | OpenCV.org,
2000–present. Available: https://opencv.org/ (accessed: 2025).
[3] OpenCV QR Code Detector API Documentation, OpenCV.org, 2024. Available: https://docs.opencv.org/(accessed: 2025).
[4] AccelStepper Library: Stepper Motor Control with Acceleration, AirSpayce, 2024. Available: https://www.airspayce.com/mikem/arduino/AccelStepper/ (https://www.airspayce.com/mikem/arduino/AccelStepper/) (accessed: 2025).
[5] Nav2 (Navigation2) ROS Package Documentation, Open Robotics, 2024. Available: https://github.com/ros-navigation/navigation2/ (https://github.com/ros-navigation/navigation2/) (accessed: 2025).
[6] S. Kohlbrecher et al., “Hector SLAM: A Flexible SLAM System for Robots and UAVs,” University of Technology Darmstadt, 2011. Available: https://wiki.ros.org/hector slam (https://wiki.ros.org/hector_slam) (accessed: 2025).
[7] USB cam ROS Package Documentation, ROS Community, 2023. Available: https://github.com/ros-drivers/usb cam (https://github.com/ros-drivers/usb_cam) (accessed: 2025).
[8] Jetson Nano Developer Kit User Guide, NVIDIA Corporation, 2024. Available: https://developer.nvidia.com/embedded/jetson-nano-developer-kit (https://developer.nvidia.com/embedded/jetson-nano-developer-kit) (accessed: 2025).
[9] RPLIDAR A1M8 Product Specifications, Slamtec, 2023. Available: https://www.slamtec.com/en/Lidar/A1 (accessed: 2025).

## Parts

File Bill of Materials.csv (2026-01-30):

Part_ID | Part_Name‬ | Manufacturer‬ | Quantity‬ | Supporting Docs / Datasheet for the‬ ‭components used‬
HW001‬ | Jetson Nano 4GB | Nvidia | 1 | https://thinkrobotics.com/products/advanced-thinkrobotics-nvidia-jetson-nano-development-kit-b01-4gb-online
HW002 | Arduino Mega 2560 | Arduino | 2 | https://robu.in/product/original-arduino-mega-2560-atmega2560-mcu-rev3/
HW003 | RPLidar A1 | ‭Slamtec | 1 | https://robu.in/product/rp-lidar-a1m8-360-degrees-laser-range-finder/
HW004 | IMU Fusion Breakout – BNO085 | Adafruit | 1 | https://robu.in/product/adafruit-9-dof-orientation-fusion-bno080-stemma-qt/
HW005 | Cytron MDD10A Dual Channel | Cytron | 2 | https://robu.in/product/dual-channel-enhanced-13amp-dc-motor-driver-30a-peak/
HW006 | Arducam 12MP USB camera | Arducam | 1 | https://robu.in/product/arduam-12mp-usb-camera-module-with-m12-lens/
HW007 | AGARO USB Extender cable 2m | Agaro | 1 | https://www.amazon.in/AGARO-Extender-Extension-High-Speed-Compatible/dp/B0B7K3KWS2
HW008 | EasyMech 100mm Modified Heavy Duty Disc Wheel | EasyMech | 1 | https://robu.in/product/modified-heavy-dutyhd-disc-wheel-100mm-dia-4pc-grey-color/
HW009 | Pro-Range 294.3 N-cm 100 RPM 12V Planetary Gear DC Motor | Pro-Range | 4 | https://robu.in/product/pro-range-planetary-gear-dc-motor-12v-100-rpm-294-3-n-cm-pgm45775-71-2k-with-encoder-me-7757ppr/
HW010 | EasyMech ID-10mm Motor Coupling Hub | EasyMech | 4 | https://robu.in/product/motor-coupling-hub-10mm-internal-dia-id/
HW011 | EasyMech Universal Bracket | EasyMech | 1 | https://robu.in/product/universal-bracket-ig42ig45-tauren-motor-straight/
HW012 | EasyMech 2000 mm 20X40 4 V Slot Aluminium Extrusion Profile | EasyMech | 1 | https://robu.in/product/easymech-2000-mm-20x40-4-v-slot-aluminium-extrusion-profile-black/
HW013 | EasyMech 1000 mm 20X20 4 T Slot Aluminium Extrusion Profile | EasyMech | 8 | https://robu.in/product/easymech-20x20-t-slot-aluminium-extrusion-profile-1000-mm/
HW014 | EasyMech M4x8mm HT Socket Button | EasyMech | 100 | https://robu.in/product/easymech-ht-socket-button-head-cap-allen-bolt-m4-x-8-25-pcs/
HW015 | EasyMech M4 MS T Nut Hammer Head For 2020 Series Aluminum Profile | EasyMech | 100 | https://robu.in/product/easymech-m4-ms-t-nut-hammer-head-for-2020-series-aluminium-extrusion-profile-10-pcs/
HW016 | EasyMech Cast Corner Bracket for 20X20 Aluminium Profile | EasyMech | 30 | https://robu.in/product/easymech-cast-corner-bracket-for-20x20-aluminium-profile-silver-4-pcs/
HW017 | Pro-Range NMC 21700 22.2V 20000mAh 3C 6S4P Li-Ion Battery Pack | Pro-Range | 1 | https://robu.in/product/pro-range-icr-18650-li-ion-20000mah-22-2v-6s8p-protected-battery-pack-3c/
HW018 | 24V/12V to 5V 5A Power Module | Robu | 1 | https://robu.in/product/24v-12v-to-5v-5a-power-module-dc-dc-xy-3606-power-converter/
HW019 | High voltage 4 Pin Rocker Switch | Robu | 1 | https://robu.in/product/high-voltage-kcd4-red-220v-16a-dpst-on-off-4-pin-rocker-switch/
HW020 | Jumper Wires | Robu | 100 | https://robu.in/product/male-to-male-jumper-wires-40-pin-30cm/
HW021 | High Quality Ultra Flexible 16AWG Silicone Wire (1 unit = 1meter) | Robu | 10 | https://robu.in/product/high-quality-ultra-flexible-16awg-silicone-wire-black/
HW022 | Two Trees TB6600 Stepper Motor Driver | Two Trees | 1 | https://robu.in/product/tb6600-stepper-motor-driver-controller-4a-942v-ttl-16-micro-step-cnc-1-axis-upgraded-version-425786-stepper-motor/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
HW023 | NEMA23 5Kg-cm Stepper Motor | Nema | 1 | https://robu.in/product/57hm41-2804-nema23-5kg-cm-stepper-motor-round-type/#tab-specification
HW024 | Two Trees Aluminum GT2 Timing Pulley | Two Trees | 1 | https://robu.in/product/aluminum-gt2-timing-pulley-6mm-belt-20-tooth-8mm-bore-2pcs/
HW025 | 10M GT2 Width 6mm Black Open Timing Belt | Robu | 1 | https://robu.in/product/10m-gt2-width-6mm-black-open-timing-belt-for-3d-printer/
HW026 | V Wheel with Plate for 2020 Aluminum Profile 3D Printer Parts | Befenybay | 1 | https://www.amazon.in/Befenybay-Aluminum-Profile-Printer-Kossel/dp/B08DJ6Y3WJ/261-5506410-1858961
HW027 | Two Trees Aluminum GT2 Timing Idler Pulley For 6mm Belt | Two Trees | 1 | https://robu.in/product/aluminum-gt2-timing-idler-pulley-6mm-belt-20-tooth-5mm-bore-2pcs/
HW028 | Roller Lever Micro Switch | Robu | 2 | https://robu.in/product/kw4-z5f100-spdt-roller-lever-micro-switch-5a1n/

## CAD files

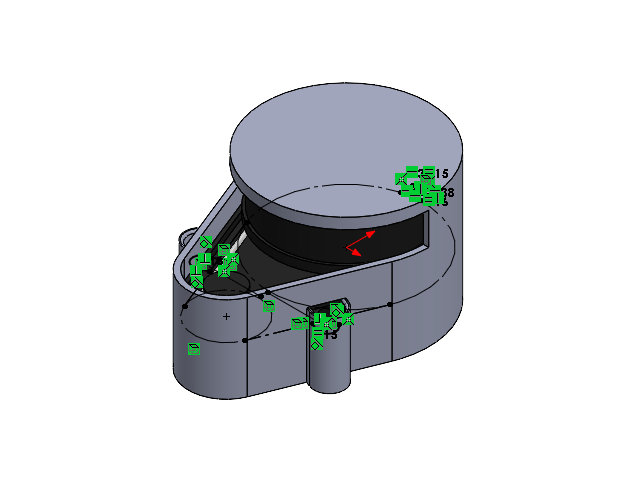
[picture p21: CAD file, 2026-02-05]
CAD_model/Components/lidar_final_assem.SLDASM
lidar
lidar_cover

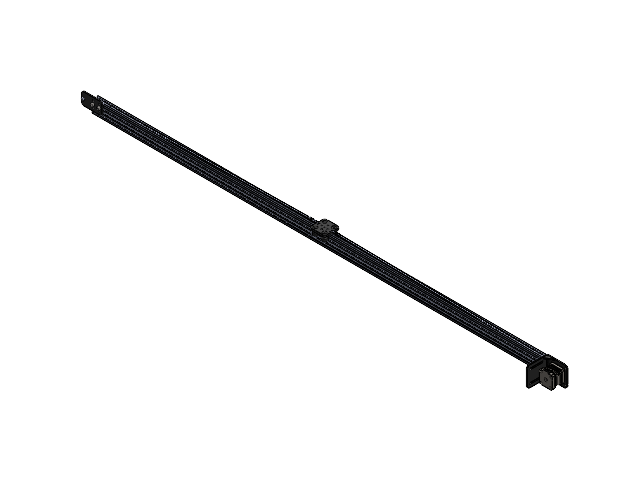
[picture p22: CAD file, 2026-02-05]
CAD_model/Components/linear_final_final_final_150.SLDASM
linear_final_150
nama_23_mounting_bracket

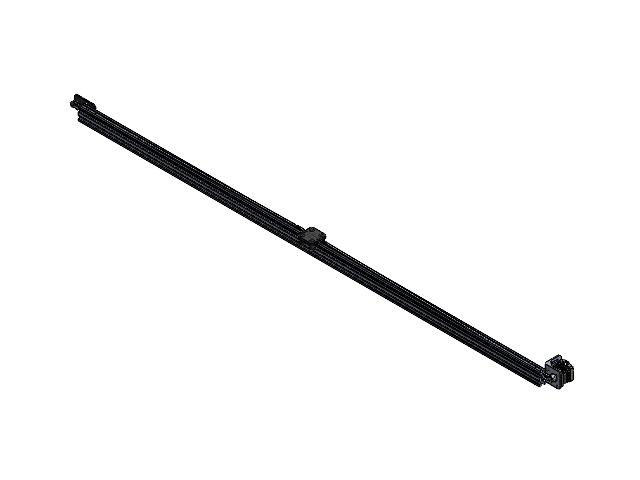
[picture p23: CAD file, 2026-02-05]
CAD_model/Components/linear_final_150.SLDASM
NEMA_17_Bracket
linear_final_150

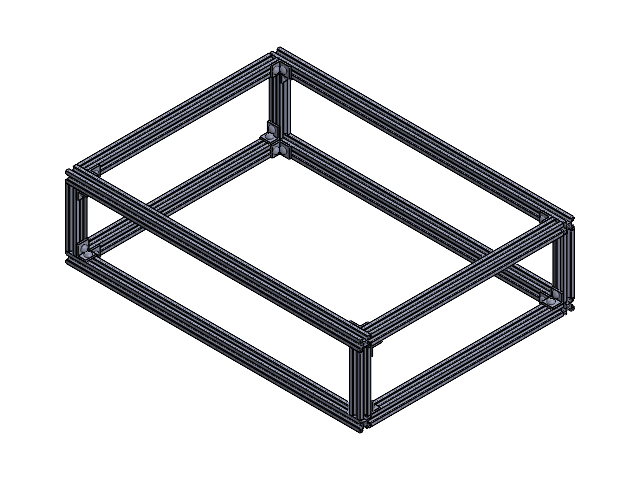
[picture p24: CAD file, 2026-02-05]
CAD_model/Components/frame.SLDASM
joint x 16
nail x 32

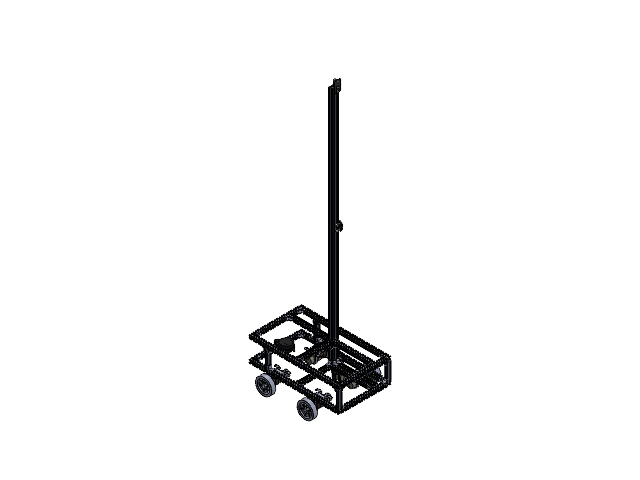
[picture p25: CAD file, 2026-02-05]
CAD_model/Components/final_assembly.SLDASM
joint x 38
nail x 76
mount x 4
motor x 4
motor_couple x 4
wheel x 4
u_clamp_1 x 4
lidar
linear_final_150
nama_23_mounting_bracket

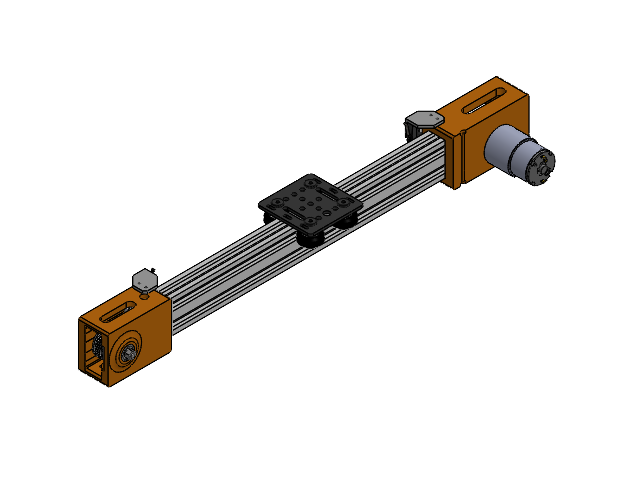
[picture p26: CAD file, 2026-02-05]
CAD_model/Components/drive_belt.SLDASM
Solid V-Wheel.stp x 4
Ball Bearing 625 2RS 5x16x5.stp x 8
Eccentric Spacer.stp x 2
1mm 5mm shim.stp x 4
6mm Spacer.stp x 2
20mm gantry plate.stp
M5x25 low profile screw.stp x 4
M5 Nylock.stp x 4
blocco_puleggia_cuscinetti.stp
puleggia_40Tb.stp x 2
%3% BS 290 - SKF 625.stp x 2
AS 1420 - 1973 - M5 x 40.stp
AS 1421 - M3 x 8 Punta a coppa.stp
limit-switch-bottomcase_MIR.stp
limit-switch-top-case_MIR.stp
pins_MIR.stp
switch_lever_MIR.stp
limit-switch-bottomcase_MIR_MIR.stp
limit-switch-top-case_MIR_MIR.stp
pins_MIR_MIR.stp
switch_lever_MIR_MIR.stp
20x40x250mm.stp
AS 1427 - M5 x 45.stp
AS 1237 - 5.stp
AS 1112 - M5 Tipo 5.stp
blocco_nema2.stp
JGB37-520_MIR_MIR.stp
blocco_finecrosa_2.stp
blocco_finecrosa_2_MIR1.stp

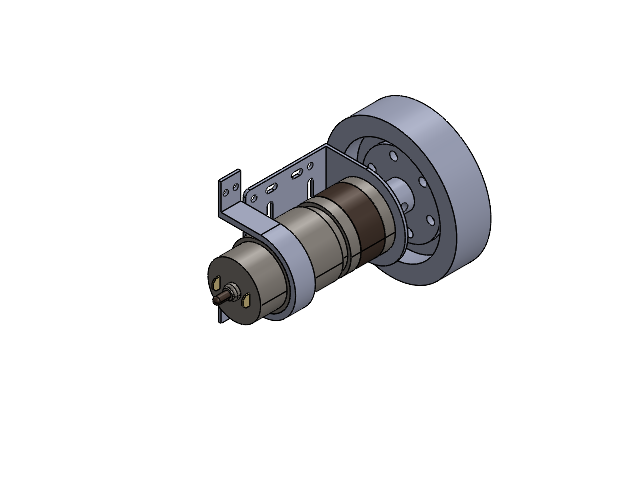
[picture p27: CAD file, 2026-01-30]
CAD_model/Components/mounted_motor.SLDASM
mount
motor
motor_couple
wheel
u_clamp_1

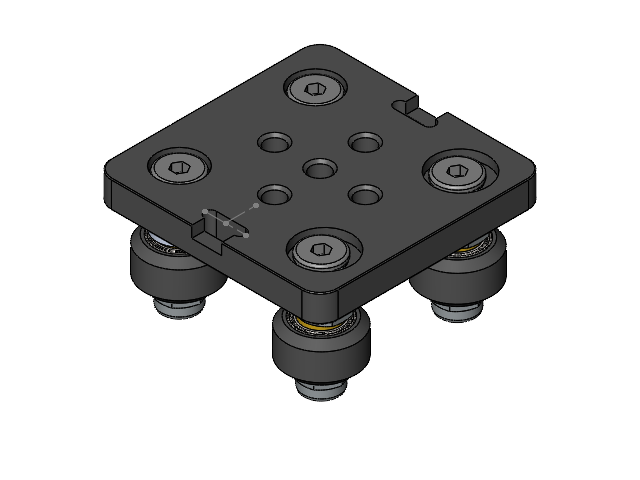
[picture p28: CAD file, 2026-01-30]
CAD_model/Components/roller.SLDASM
MVG-P1
MVG-P2 x 4
MVG-P3 x 2
MVG-P4 x 4
MVG-P5 x 2
MVG-P6 x 4
MVG-P7 x 4

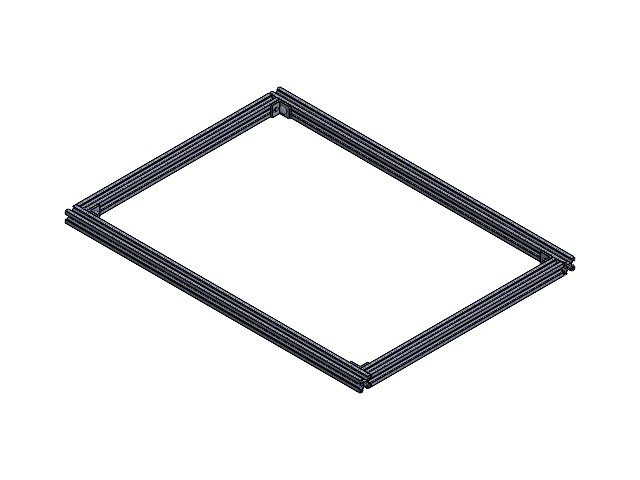
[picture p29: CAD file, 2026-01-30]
CAD_model/Components/base_new.SLDASM
joint x 4
nail x 4

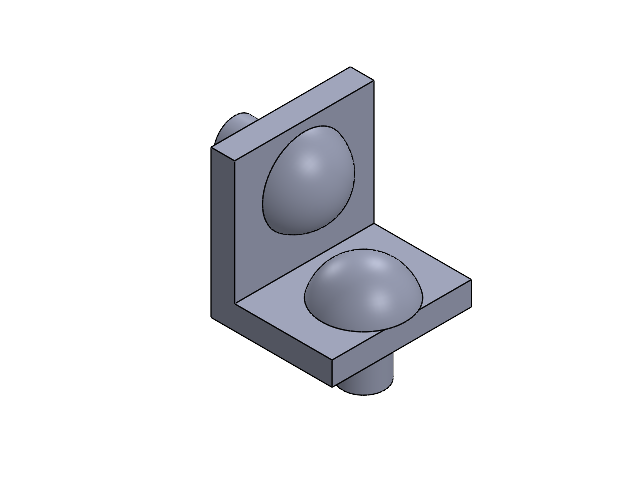
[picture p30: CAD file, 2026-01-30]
CAD_model/Components/complete_joint.SLDASM
nail x 2
joint

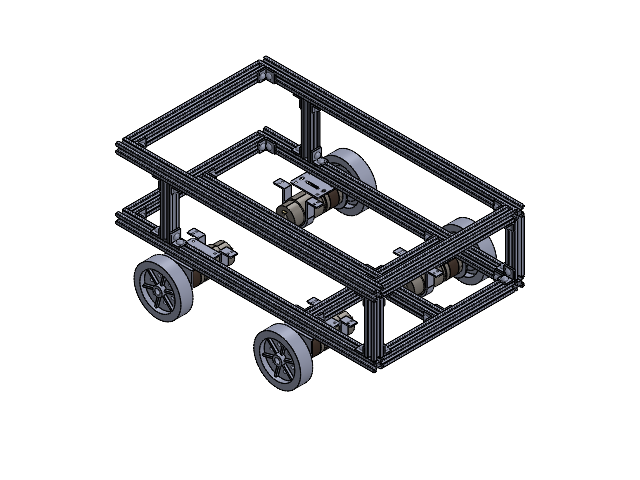
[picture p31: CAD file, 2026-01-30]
CAD_model/Components/amr_with_wheels.SLDASM
joint x 36
nail x 72
mount x 4
motor x 4
motor_couple x 4
wheel x 4
u_clamp_1 x 4

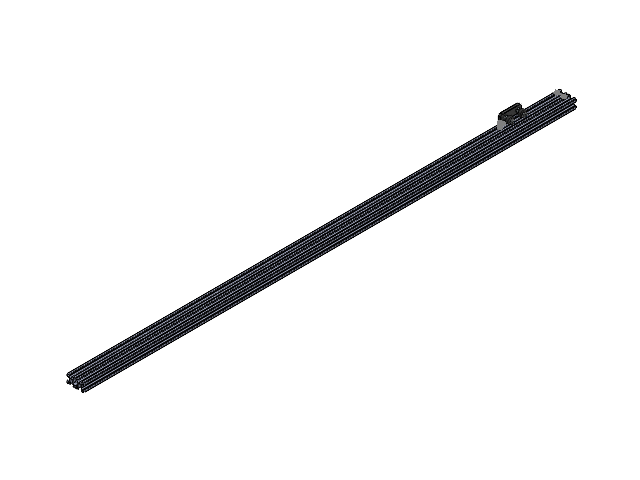
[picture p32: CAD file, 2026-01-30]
CAD_model/Components/double_extrusion.SLDASM
MVG-P1
MVG-P2 x 4
MVG-P3 x 2
MVG-P4 x 4
MVG-P5 x 2
MVG-P6 x 4
MVG-P7 x 4

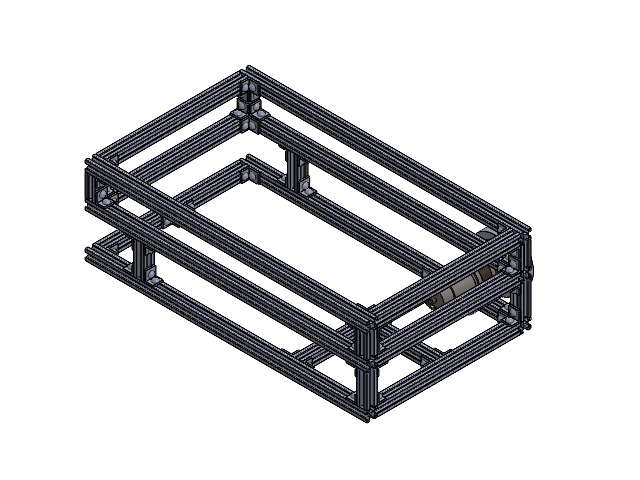
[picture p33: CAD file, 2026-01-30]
CAD_model/Components/amr1.SLDASM
joint x 56
nail x 110
mount
motor
motor_couple
wheel

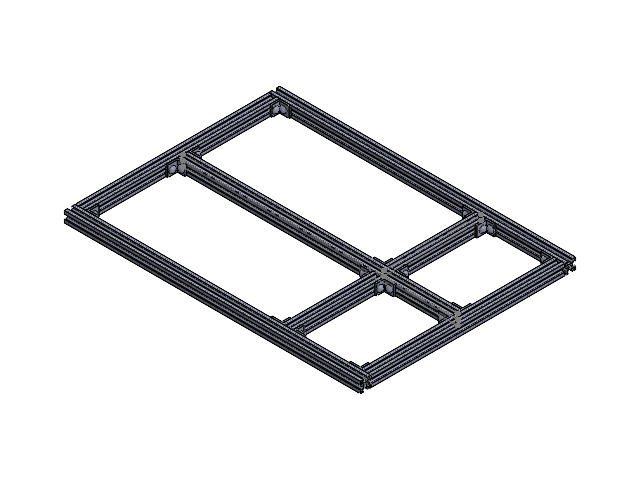
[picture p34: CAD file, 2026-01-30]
CAD_model/Components/base_modified_1.SLDASM
joint x 16
nail x 32

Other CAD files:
CAD_model/Components/base.SLDASM
CAD_model/Components/double_extrusion_rods.SLDASM
CAD_model/Components/base_modified_3.SLDASM
CAD_model/Components/base_modified_2.SLDASM
CAD_model/Components/11.SLDPRT
CAD_model/Components/15.SLDPRT
CAD_model/Components/17.SLDPRT
CAD_model/Components/22.4.SLDPRT
CAD_model/Components/24.5.SLDPRT
CAD_model/Components/3.6.SLDPRT
CAD_model/Components/36.SLDPRT
CAD_model/Components/4.5 - Copy.SLDPRT
CAD_model/Components/4.5.SLDPRT
CAD_model/Components/51.SLDPRT
CAD_model/Components/55.SLDPRT
CAD_model/Components/Aluminum Spacer 3mm[1].SLDPRT
CAD_model/Components/Aluminum Spacer 6mm[1].SLDPRT
CAD_model/Components/Aluminum Spacer 6mm[2].SLDPRT
CAD_model/Components/Ball Bearing 5 x 16 x 5[10].SLDPRT
CAD_model/Components/Ball Bearing 5 x 16 x 5[1].SLDPRT
CAD_model/Components/Ball Bearing 5 x 16 x 5[2].SLDPRT
CAD_model/Components/Ball Bearing 5 x 16 x 5[3].SLDPRT
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

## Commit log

2026-01-30 Update and rename BOM_Itemized.csv to Bill of Materials.csv
    [Bill of Materials.csv]
2026-03-01 Add links to hardware demo and CAD model
